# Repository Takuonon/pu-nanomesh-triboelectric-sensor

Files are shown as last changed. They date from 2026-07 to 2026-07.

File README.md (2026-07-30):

# All-PU Nanomesh Triboelectric Throat Sensor

This repository provides hardware, firmware, and software information for the
wireless acquisition system used with a triboelectric sensor. For the scientific
background, device concept, experimental results, and interpretation, please
refer to the associated paper.

If you use or refer to any part of this repository, please cite the paper listed
in the [Citation](#citation) section at the end of this README.

## Contents

```text
hardware/
  gerber/                       PCB fabrication outputs for the TENG module
firmware/
  xiao_nrf52840/
    xiao_nrf52840.ino           Arduino firmware for Seeed XIAO nRF52840
software/
  pyqt_gui/
    app.py                      PyQt GUI entry point
    data_source.py              Source interface used by the GUI
    data_source_ble.py          BLE acquisition backend
    ui_main.py                  GUI layout, plotting, filtering, CSV export
    requirements.txt            Python dependencies
docs/
  images/
    Analog_circuit.pdf          Analog front-end and MCU schematic
    FPCB.pdf                    Wireless module and FPCB design figure
    *.png                       README preview images generated from the PDFs
```

## Hardware

The hardware release provides the analog circuit figure, the wireless module
FPCB figure, and the PCB fabrication package for the TENG module. The Gerber job
file identifies the design as `TENG_module`, generated by KiCad 9.0.6.

### Circuit Configuration

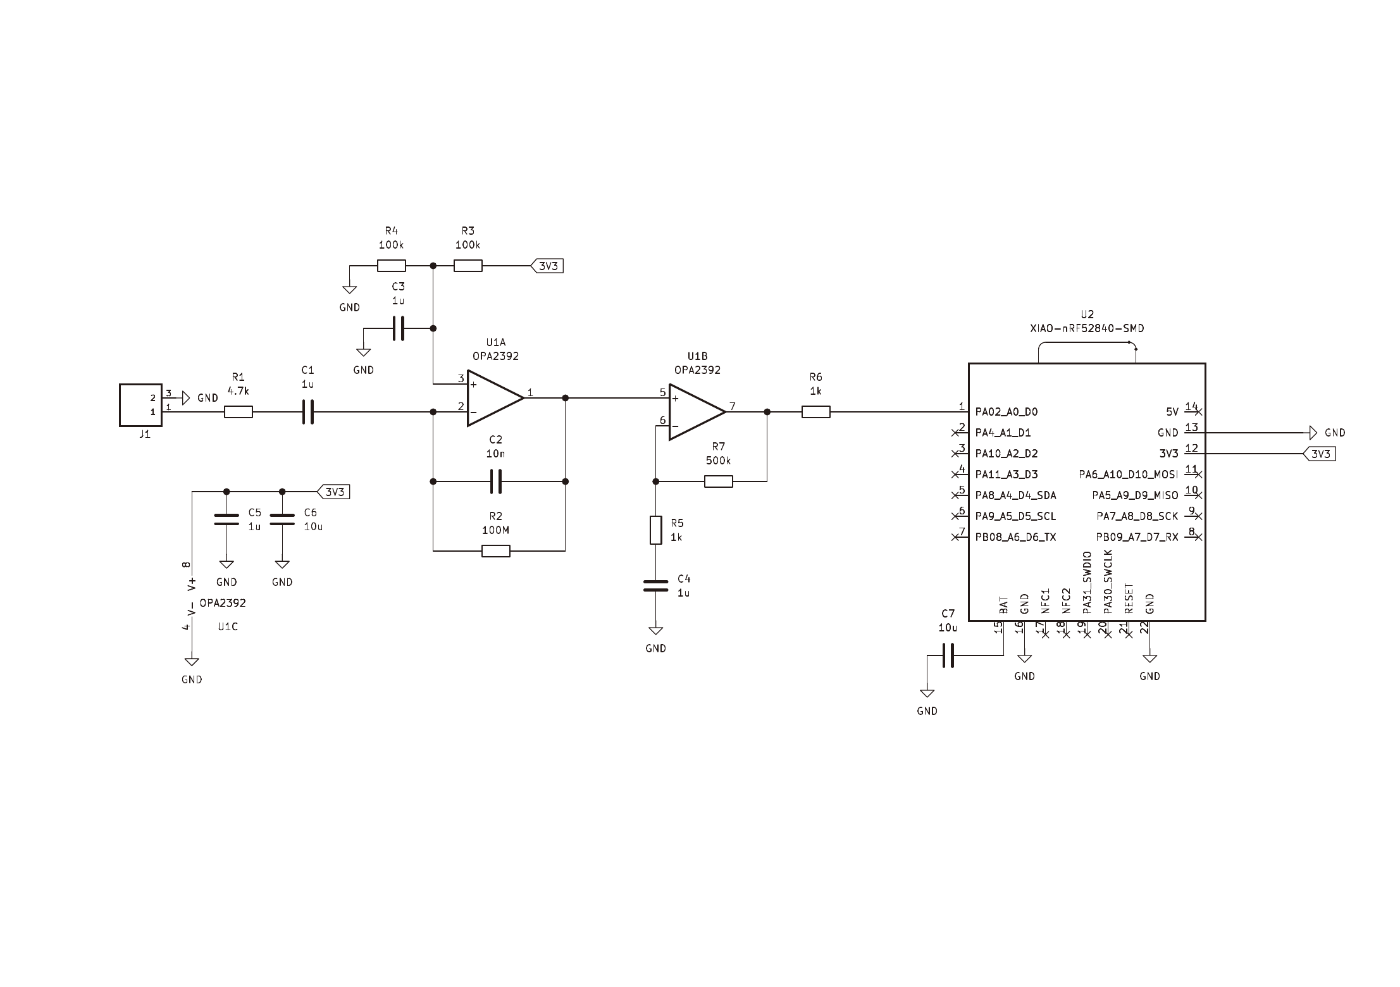
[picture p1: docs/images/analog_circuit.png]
Analog circuit


Source figure: [`Analog_circuit.pdf`](docs/images/Analog_circuit.pdf)

The acquisition circuit receives the triboelectric sensor output through the
input connector and routes it to an OPA2392-based two-stage analog front end.
The first stage is configured as a charge-amplifier stage for the high-impedance
triboelectric signal. The second stage provides voltage amplification and
conditioning before the signal is connected to the `A0` analog input of the
Seeed Studio XIAO nRF52840.

The XIAO nRF52840 performs ADC sampling for the conditioned triboelectric sensor
signal and sends the acquired data to the PC over BLE. The XIAO on-board PDM
microphone is used as the second acquisition channel in the firmware and GUI.

### Bill of Materials

| No. | Qty. | Description | Designator | Footprint | Value | Manufacturer Part | Manufacturer | Supplier Part | Supplier |
| --- | --- | --- | --- | --- | --- | --- | --- | --- | --- |
| 1 | 2 | SMD thin-film resistor | R5, R6 | R_0603 | 1 kOhm | ERA3AEB102V | Panasonic | C190613 | LCSC |
| 2 | 1 | SMD thin-film resistor | R1 | R_0603 | 4.7 kOhm | ERA3AEB472V | Panasonic | C473239 | LCSC |
| 3 | 2 | SMD thin-film resistor | R3, R4 | R_0603 | 100 kOhm | ERA3AEB104V | Panasonic | C190609 | LCSC |
| 4 | 1 | SMD thick-film resistor | R7 | R_0603 | 499 kOhm | ERJ3EKF4993V | Panasonic | C278628 | LCSC |
| 5 | 1 | SMD thick-film resistor | R2 | R_0805 | 100 MOhm | 0805W8F1006T5E | UNI-ROYAL | C169373 | LCSC |
| 6 | 1 | SMD capacitor | C2 | C_0603 | 10 nF | GRM1885C1H103JA01D | Murata | C85973 | LCSC |
| 7 | 4 | SMD capacitor | C1, C3, C4, C5 | C_0603 | 1 uF | GCM188R71E105KA64D | Murata | C85862 | LCSC |
| 8 | 2 | SMD capacitor | C6, C7 | C_0603 | 10 uF | GRM188Z71A106KA73D | Murata | C2959727 | LCSC |
| 9 | 1 | Operational amplifier | U1 |  | OPA2392DR | OPA2392DR | Texas Instruments | C22428420 | LCSC |
| 10 | 1 | BLE microcontroller module | U2 |  | Seeed Studio XIAO nRF52840 Sense |  | Seeed Studio |  | JD.com |
| 11 | 1 | Spring terminal block | J1 |  |  | 2059-302/998-403 | WAGO | C2765060 | LCSC |
| 12 | 1 | Lithium polymer battery |  |  | 3.7 V, 100 mAh | 302020-100mah | Taisko | C19632322 | LCSC |

### FPCB Design

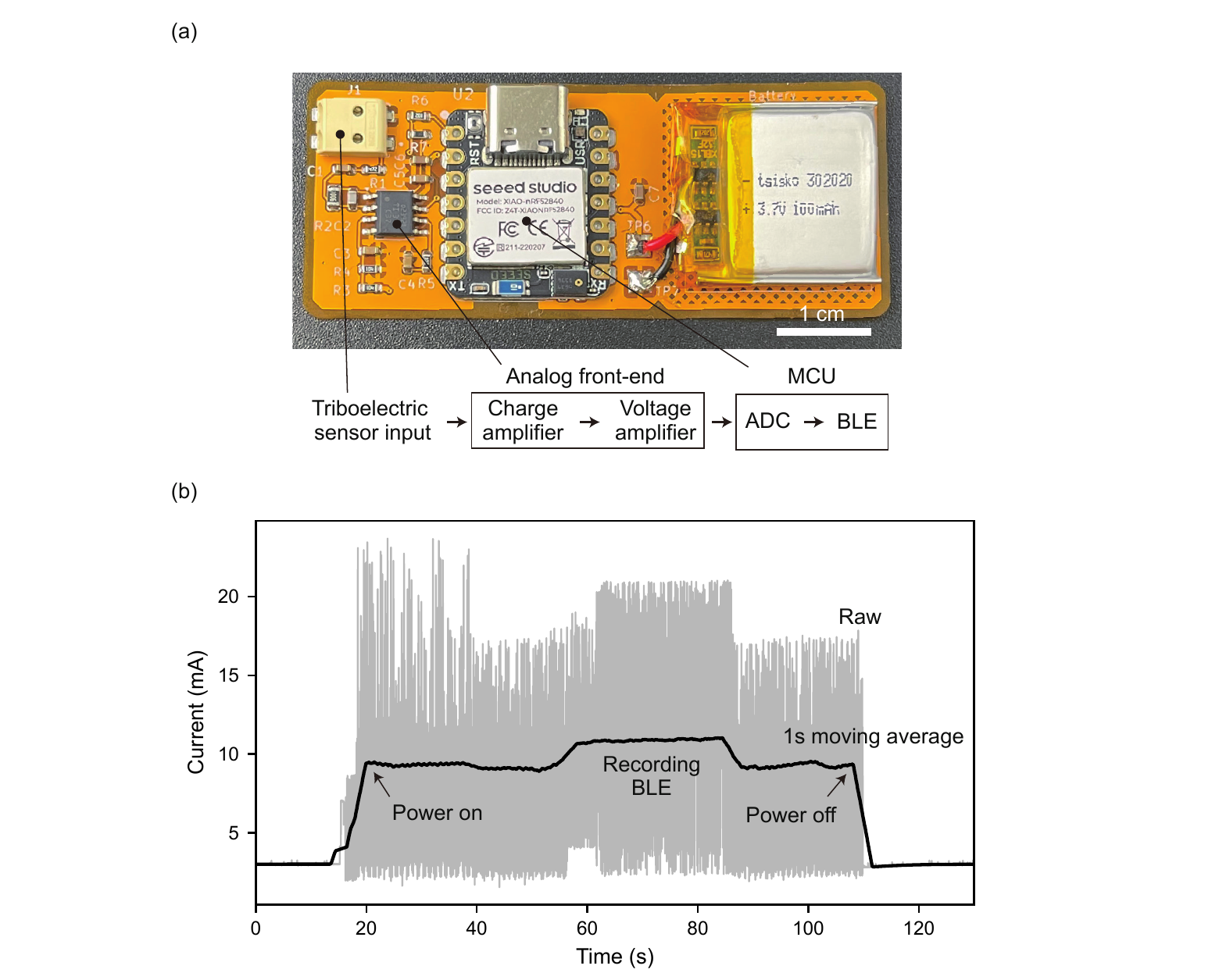
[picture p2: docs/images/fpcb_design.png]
FPCB design


Source figure: [`FPCB.pdf`](docs/images/FPCB.pdf)

Figure (a) shows the wireless module implemented on the FPCB. The board
integrates the triboelectric sensor input connector, the analog front-end
components, the XIAO nRF52840 module, and a small battery connection. The signal
flow is:

```text
Triboelectric sensor input -> charge amplifier -> voltage amplifier -> ADC -> BLE
```

Figure (b) shows the current consumption during module operation. The operating
current was approximately 10 mA; with a 100 mAh battery, the expected operating
time was approximately 10 h per charge.

Board metadata from `hardware/gerber/TENG_module-job.gbrjob`:

- Board size: 63.05 mm x 26.05 mm
- Layer count: 2 copper layers
- Board thickness: 1.6 mm
- Fabrication files: top/bottom copper, solder mask, solder paste, silkscreen,
  edge cuts, plated drill, non-plated drill, and Gerber job metadata

### Circuit Role

The hardware files describe the sensor-module PCB used with the all-PU
nanomesh triboelectric throat sensor. In the acquisition workflow, the sensor
signal is conditioned by the analog front end and connected to the XIAO
nRF52840 analog input (`A0`) as channel 1. The XIAO on-board PDM microphone is
used as channel 2 for simultaneous reference audio acquisition.

For analog acquisition, the firmware expects the channel-1 signal to stay
within the XIAO nRF52840 ADC input range. If a mid-supply bias is used by the
analog front end, the GUI subtracts the mean of channel 1 after capture for
visualization.

## Firmware

Firmware path: `firmware/xiao_nrf52840/xiao_nrf52840.ino`

The firmware turns a Seeed Studio XIAO nRF52840 into a BLE peripheral named
`XIAO-AUDIO`. It records two channels and transfers the captured block to the PC
after recording.

### Firmware Design Policy

- Keep the microcontroller workflow deterministic: record first, then transfer.
- Use fixed-size buffers to avoid dynamic allocation during acquisition.
- Store both channels against a shared 8 kHz sample index.
- Discard the first 1 s of samples as warm-up to reduce startup transients.
- Use BLE indications for acknowledged transfer rather than unacknowledged
  notifications.
- Keep the BLE protocol small: one control byte starts capture or shutdown.

### Sampling

- Channel 1: SAADC on `A0`, sampled at 8 kHz
- Channel 2: on-board PDM microphone, captured at 16 kHz and decimated by 2
- Storage and transfer rate: 8 kHz per channel
- Maximum stored samples: 32,000 samples per channel
- Maximum capture duration: 4 s
- Warm-up discard: 1 s before storing the requested capture window

### BLE Protocol

Service UUID:

```text
19B20000-E8F2-537E-4F6C-D104768A1214
```

CTRL characteristic, PC to XIAO:

```text
19B20001-E8F2-537E-4F6C-D104768A1214
```

Payload:

- `0x01` to `0x04`: capture duration in seconds
- `0xFF`: enter low-power System OFF

AUDIO characteristic, XIAO to PC:

```text
19B20002-E8F2-537E-4F6C-D104768A1214
```

Each AUDIO packet contains:

1. `seq`: 2-byte little-endian sequence number
2. `payload`: stereo interleaved little-endian `int16` samples

The payload format is:

```text
[ch1_0, ch2_0, ch1_1, ch2_1, ...]
```

The current firmware sends 50 stereo frames per packet, corresponding to 200
payload bytes plus the 2-byte sequence number.

### LED States

- Disconnected idle: red blink
- Connected idle: blue blink
- Recording: solid blue
- Transferring: solid green
- Shutdown acknowledgement: brief purple indication

## Software

Software path: `software/pyqt_gui/`

The PC software is a PyQt6 GUI that connects to the XIAO nRF52840 over BLE,
requests a capture, receives the interleaved two-channel data, and displays the
waveforms.

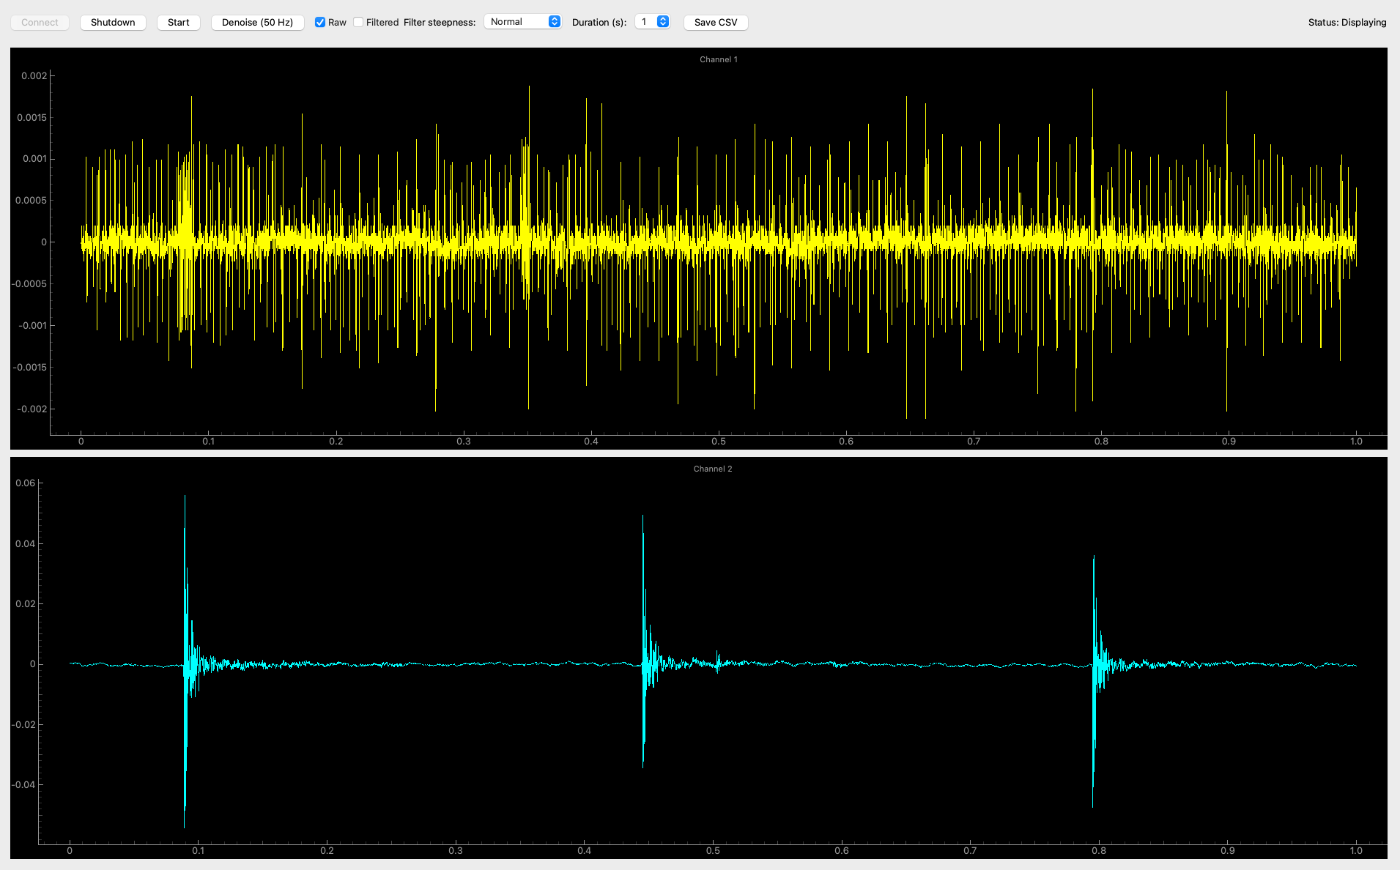
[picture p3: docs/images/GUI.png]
PyQt GUI


The GUI displays simultaneous two-channel recordings: the triboelectric sensor
signal in the upper yellow trace and the PDM microphone signal in the lower blue
trace.

### Software Design Policy

- Keep the UI independent from the acquisition backend through `BaseSource`.
- Use Bleak for BLE central-mode scanning, connection, control writes, and
  indication subscription.
- Convert received little-endian `int16` PCM data to normalized `float32` data
  for plotting.
- Display captured data only after the firmware completes record-then-transfer.
- Provide optional 50 Hz bandstop filtering for visual inspection.
- Preserve raw data and allow CSV export of the displayed two-channel buffer.

### Python Setup

The pinned requirements are macOS-oriented because BLE access through Bleak on
CoreBluetooth uses the `pyobjc` packages.

From the repository root:

```bash
python -m venv .venv
source .venv/bin/activate
python -m pip install -r software/pyqt_gui/requirements.txt
```

### Run

From the repository root:

```bash
python -m software.pyqt_gui.app
```

The GUI starts in BLE mode, attempts to connect to `XIAO-AUDIO`, and enables
capture controls after the BLE connection is ready. Select a duration from 1 to
4 s and press `Start`.

## Data Format

The received waveform data are two-channel, interleaved `int16` samples:

```text
seq_lsb seq_msb ch1_lsb ch1_msb ch2_lsb ch2_msb ...
```

The GUI converts this byte stream into a NumPy array with shape `(N, 2)`.
Channel 1 is the ADC input; channel 2 is the PDM microphone input.

## Notes

- The firmware uses a record-then-transfer workflow, so transfer begins only
  after acquisition is complete.
- A requested 4 s capture includes an additional 1 s warm-up discard before the
  stored samples are collected.
- BLE indications improve transfer reliability but may be slower than
  notifications.
- The current release contains fabrication outputs for the PCB. If editable CAD
  source files are needed, add them separately from the Gerber package.

## Citation

If you use or refer to any part of this repository in a publication,
presentation, thesis, dataset, or derived research project, please cite the
following paper, which describes the sensor system associated with these files:

```text
Takuo Tachibana, Yusuke Ebihara, Yi Kao, Manabu Ezumi, Yan Li,
Kento Yamagishi, Tomoyuki Yokota, Tian-Ling Ren, and Takao Someya,
"An All-Polyurethane Nanomesh Triboelectric Sensor for Swallowing and Voice Detection."
```

The citation information will be updated with journal, year, volume, pages, and
DOI after publication.

## License

The software, firmware, and circuit design files in this repository may be used
for research purposes.

See `LICENSE` for the full license text.

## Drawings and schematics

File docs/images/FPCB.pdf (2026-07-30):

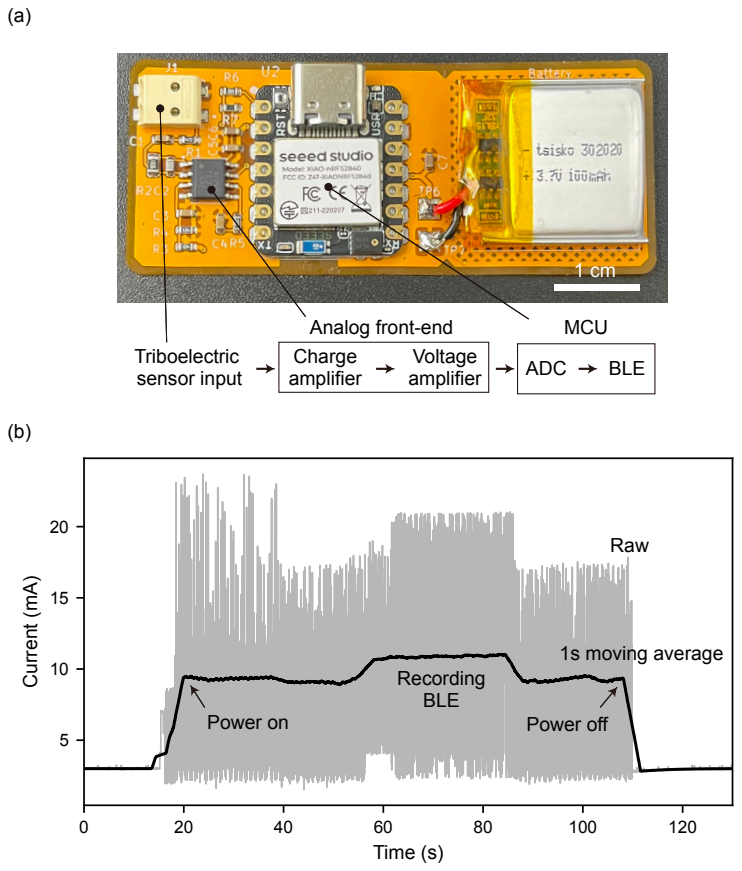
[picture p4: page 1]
Time (s); Current (mA); Raw; 1s moving average; Power on; Power off; Recording BLE; Triboelectric sensor input; Charge amplifier; Voltage; amplifier; ADC; BLE; Analog front-end; MCU

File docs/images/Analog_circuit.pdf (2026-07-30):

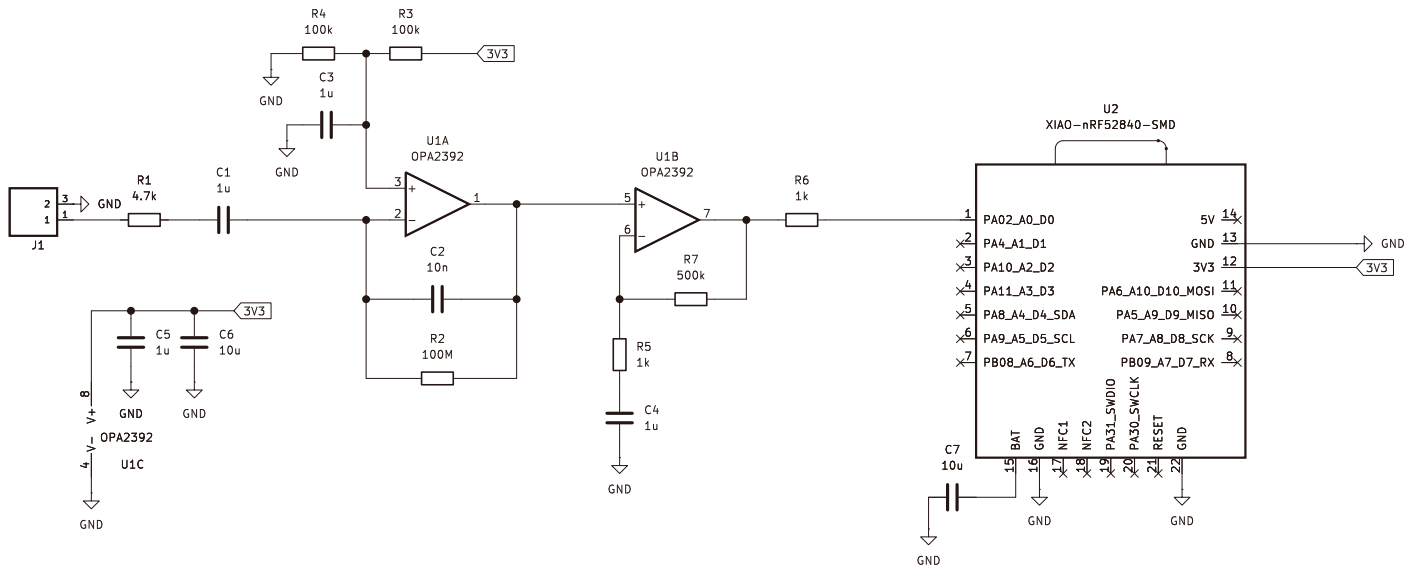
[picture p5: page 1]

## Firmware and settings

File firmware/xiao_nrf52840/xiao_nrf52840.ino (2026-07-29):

#include <Arduino.h>
#include <ArduinoBLE.h>
#include <PDM.h>

extern "C" {
  #include "nrfx_ppi.h"
  #include "nrf_saadc.h"
  #include "nrf_timer.h"
}

// ===================== BLE UUID =====================
BLEService audioService("19B20000-E8F2-537E-4F6C-D104768A1214");

BLEByteCharacteristic ctrlChar(
  "19B20001-E8F2-537E-4F6C-D104768A1214",
  BLERead | BLEWrite
);

BLECharacteristic audioChar(
  "19B20002-E8F2-537E-4F6C-D104768A1214",
  BLEIndicate,
  244
);

// ===================== Settings =====================
static const int PDM_CAPTURE_RATE = 16000;
static const int ADC_CAPTURE_RATE = 8000;
static const int STORE_RATE = 8000;

static const int MAX_NUM_SAMPLES = 32000;
static const int MAX_REC_SECONDS = MAX_NUM_SAMPLES / STORE_RATE; // 4

static constexpr uint32_t CHUNK_SAMPLES = 1024;
static const float WARMUP_DROP_SECONDS = 1.0f;

static const int PAYLOAD_BYTES = 200;
static const int FRAMES_PER_PKT = PAYLOAD_BYTES / 4;

// Shutdown command uses a value outside the normal capture-duration range.
static const byte CMD_SHUTDOWN = 0xFF; // 255

// ===================== Buffers =====================
static int16_t ch1_adc[MAX_NUM_SAMPLES];
static int16_t ch2_pdm[MAX_NUM_SAMPLES];

static volatile int adcWritten = 0;
static volatile int pdmWritten = 0;

static int16_t pdmBuf[256];

static int16_t saadcBuf0[CHUNK_SAMPLES];
static int16_t saadcBuf1[CHUNK_SAMPLES];
static int16_t* activeBuf = saadcBuf0;
static int16_t* nextBuf   = saadcBuf1;

// ===================== Recording control =====================
static volatile bool recording = false;
static volatile int targetSamples = STORE_RATE;
static volatile int warmupDropPDM = 0;
static volatile int warmupDropADC = 0;

static volatile uint8_t pdmDecimPhase = 0;

// ===================== TIMER4 + PPI =====================
static NRF_TIMER_Type* const TMR = NRF_TIMER4;
static nrf_ppi_channel_t ppiCh;

// ===================== LED =====================
static const bool LED_ACTIVE_LOW = true;

enum DeviceState {
  STATE_IDLE_DISCONNECTED = 0,
  STATE_IDLE_CONNECTED = 1,
  STATE_RECORDING = 2,
  STATE_COMMUNICATING = 3,
};

static DeviceState gState = STATE_IDLE_DISCONNECTED;
static unsigned long gBlinkLastMs = 0;
static bool gBlinkOn = false;

static inline void ledWrite(uint8_t pin, bool on) {
  if (LED_ACTIVE_LOW) digitalWrite(pin, on ? LOW : HIGH);
  else digitalWrite(pin, on ? HIGH : LOW);
}
static inline void ledsAllOff() {
  ledWrite(LEDR, false);
  ledWrite(LEDG, false);
  ledWrite(LEDB, false);
}
static void setState(DeviceState st) {
  gState = st;
  if (gState == STATE_RECORDING) {
    ledWrite(LEDR, false); ledWrite(LEDG, false); ledWrite(LEDB, true);   // blue
  } else if (gState == STATE_COMMUNICATING) {
    ledWrite(LEDR, false); ledWrite(LEDG, true);  ledWrite(LEDB, false);  // green
  } else {
    ledsAllOff();
    gBlinkLastMs = millis();
    gBlinkOn = false;
  }
}
static void updateIdleBlink() {
  if (gState != STATE_IDLE_DISCONNECTED && gState != STATE_IDLE_CONNECTED) return;
  const unsigned long now = millis();
  if (now - gBlinkLastMs >= 500) {
    gBlinkLastMs = now;
    gBlinkOn = !gBlinkOn;
    if (gState == STATE_IDLE_DISCONNECTED) {
      ledWrite(LEDR, gBlinkOn); ledWrite(LEDG, false); ledWrite(LEDB, false);
    } else {
      ledWrite(LEDR, false); ledWrite(LEDG, false); ledWrite(LEDB, gBlinkOn);
    }
  }
}

// ===================== PDM callback =====================
void onPDMdata() {
  int bytesAvailable = PDM.available();
  if (bytesAvailable <= 0) return;

  int samples = bytesAvailable / 2;
  if (samples > (int)(sizeof(pdmBuf) / sizeof(pdmBuf[0]))) {
    samples = sizeof(pdmBuf) / sizeof(pdmBuf[0]);
  }
  PDM.read(pdmBuf, samples * 2);

  if (!recording) return;

  for (int i = 0; i < samples; i++) {
    if (warmupDropPDM > 0) {
      warmupDropPDM--;
      if (warmupDropPDM == 0) {
        pdmDecimPhase = 0;
      }
      continue;
    }

    if (pdmDecimPhase) {
      pdmDecimPhase = 0;
      continue;
    }
    pdmDecimPhase = 1;

    int idx = pdmWritten;
    if (idx >= targetSamples) {
      return;
    }
    ch2_pdm[idx] = pdmBuf[i];
    pdmWritten++;
  }
}

// ===================== SAADC init (register) =====================
static void timer4_init_16khz() {
  TMR->TASKS_STOP  = 1;
  TMR->TASKS_CLEAR = 1;
  TMR->MODE      = TIMER_MODE_MODE_Timer;
  TMR->BITMODE   = TIMER_BITMODE_BITMODE_32Bit;
  TMR->PRESCALER = 0;
  TMR->CC[0]     = 16000000UL / ADC_CAPTURE_RATE;
  TMR->SHORTS    = TIMER_SHORTS_COMPARE0_CLEAR_Msk;
  TMR->EVENTS_COMPARE[0] = 0;
}

static void saadc_init_ain0_reg() {
  NRF_SAADC->ENABLE = (SAADC_ENABLE_ENABLE_Enabled << SAADC_ENABLE_ENABLE_Pos);
  NRF_SAADC->RESOLUTION = SAADC_RESOLUTION_VAL_12bit;

  NRF_SAADC->CH[0].PSELP = SAADC_CH_PSELP_PSELP_AnalogInput0;
  NRF_SAADC->CH[0].PSELN = SAADC_CH_PSELN_PSELN_NC;

  NRF_SAADC->CH[0].CONFIG =
      (SAADC_CH_CONFIG_REFSEL_Internal << SAADC_CH_CONFIG_REFSEL_Pos) |
      (SAADC_CH_CONFIG_GAIN_Gain1_6     << SAADC_CH_CONFIG_GAIN_Pos)   |
      (SAADC_CH_CONFIG_TACQ_10us        << SAADC_CH_CONFIG_TACQ_Pos)   |
      (SAADC_CH_CONFIG_MODE_SE          << SAADC_CH_CONFIG_MODE_Pos)   |
      (SAADC_CH_CONFIG_RESP_Bypass      << SAADC_CH_CONFIG_RESP_Pos)   |
      (SAADC_CH_CONFIG_RESN_Bypass      << SAADC_CH_CONFIG_RESN_Pos);

  activeBuf = saadcBuf0;
  nextBuf   = saadcBuf1;

  NRF_SAADC->RESULT.PTR    = (uint32_t)activeBuf;
  NRF_SAADC->RESULT.MAXCNT = CHUNK_SAMPLES;

  NRF_SAADC->EVENTS_END = 0;
  NRF_SAADC->EVENTS_STARTED = 0;
}

static void ppi_connect_timer_to_saadc_sample() {
  nrfx_ppi_channel_alloc(&ppiCh);
  const uint32_t evt_addr  = (uint32_t)&TMR->EVENTS_COMPARE[0];
  const uint32_t task_addr = (uint32_t)&NRF_SAADC->TASKS_SAMPLE;
  nrfx_ppi_channel_assign(ppiCh, evt_addr, task_addr);
  nrfx_ppi_channel_enable(ppiCh);
}

static inline void consume_saadc_samples(const int16_t* buf, int n) {
  for (int i = 0; i < n; i++) {
    if (warmupDropADC > 0) {
      warmupDropADC--;
      continue;
    }
    int idx = adcWritten;
    if (idx >= targetSamples) return;
    ch1_adc[idx] = buf[i];
    adcWritten++;
  }
}

// ===================== Record control =====================
static bool startRecordingBoth(int seconds) {
  if (seconds < 1) seconds = 1;
  if (seconds > MAX_REC_SECONDS) seconds = MAX_REC_SECONDS;

  targetSamples = STORE_RATE * seconds;

  adcWritten = 0;
  pdmWritten = 0;

  warmupDropPDM = (int)(PDM_CAPTURE_RATE * WARMUP_DROP_SECONDS);
  warmupDropADC = (int)(ADC_CAPTURE_RATE * WARMUP_DROP_SECONDS);
  pdmDecimPhase = 0;

  recording = true;

  PDM.onReceive(onPDMdata);
  if (!PDM.begin(1, PDM_CAPTURE_RATE)) {
    recording = false;
    return false;
  }

  NRF_SAADC->EVENTS_CALIBRATEDONE = 0;
  NRF_SAADC->TASKS_CALIBRATEOFFSET = 1;
  delay(10);

  NRF_SAADC->EVENTS_STARTED = 0;
  NRF_SAADC->TASKS_START = 1;
  for (volatile int i = 0; i < 20000 && NRF_SAADC->EVENTS_STARTED == 0; i++) {}

  NRF_SAADC->TASKS_SAMPLE = 1;

  TMR->TASKS_CLEAR = 1;
  TMR->TASKS_START = 1;

  return true;
}

static void stopRecordingBoth() {
  recording = false;

  TMR->TASKS_STOP = 1;
  NRF_SAADC->TASKS_STOP = 1;
  PDM.end();
}

// ===================== Low-power shutdown =====================
// Enter this path when CMD_SHUTDOWN (255) is received over BLE.
// Wake-up from System OFF requires pressing RESET or power-cycling the board.
static void enterSystemOffNow() {
  // Show shutdown acknowledgement in purple (red + blue).
  ledWrite(LEDR, true);
  ledWrite(LEDG, false);
  ledWrite(LEDB, true);
  delay(150);  // Briefly visible to the user.

  // Turn LEDs off just before shutdown.
  ledsAllOff();
  delay(50);

  // Stop peripherals defensively.
  stopRecordingBoth();
  nrfx_ppi_channel_disable(ppiCh);
  NRF_SAADC->ENABLE = (SAADC_ENABLE_ENABLE_Disabled << SAADC_ENABLE_ENABLE_Pos);

  // Give BLE a short grace period to stop cleanly.
  BLE.stopAdvertise();
  BLE.disconnect();
  delay(100);

  // Enter System OFF.
  NRF_POWER->SYSTEMOFF = 1;

  // Execution should not return here.
  while (1) {}
}

// ===================== Send: stereo interleave =====================
static void sendRecordedStereoInterleaved(int nSamples) {
  uint16_t seq = 0;
  uint8_t packet[2 + FRAMES_PER_PKT * 4];

  int idx = 0;
  while (idx < nSamples) {
    int frames = nSamples - idx;
    if (frames > FRAMES_PER_PKT) frames = FRAMES_PER_PKT;

    packet[0] = (uint8_t)(seq & 0xFF);
    packet[1] = (uint8_t)((seq >> 8) & 0xFF);

    uint8_t* p = packet + 2;
    for (int i = 0; i < frames; i++) {
      int16_t a = ch1_adc[idx + i];
      int16_t b = ch2_pdm[idx + i];

      *p++ = (uint8_t)(a & 0xFF);
      *p++ = (uint8_t)((a >> 8) & 0xFF);
      *p++ = (uint8_t)(b & 0xFF);
      *p++ = (uint8_t)((b >> 8) & 0xFF);
    }

    audioChar.writeValue(packet, 2 + frames * 4);
    idx += frames;
    seq++;
    delay(5);
  }
}

// ===================== BLE main =====================
void setup() {
  Serial.begin(115200);
  unsigned long t0 = millis();
  while (!Serial && (millis() - t0) < 2000) delay(10);

  pinMode(LEDR, OUTPUT);
  pinMode(LEDG, OUTPUT);
  pinMode(LEDB, OUTPUT);
  ledsAllOff();
  setState(STATE_IDLE_DISCONNECTED);

  timer4_init_16khz();
  saadc_init_ain0_reg();
  ppi_connect_timer_to_saadc_sample();

  if (!BLE.begin()) {
    Serial.println("BLE.begin failed");
    while (1) {}
  }

  BLE.setLocalName("XIAO-AUDIO");
  BLE.setDeviceName("XIAO-AUDIO");
  BLE.setAdvertisedService(audioService);

  audioService.addCharacteristic(ctrlChar);
  audioService.addCharacteristic(audioChar);
  BLE.addService(audioService);

  ctrlChar.writeValue((byte)0);

  BLE.advertise();
  Serial.println("BLE Audio Peripheral Ready (ADC ch1 + PDM ch2, interleaved)");
}

void loop() {
  BLEDevice central = BLE.central();
  if (!central) {
    if (gState != STATE_IDLE_DISCONNECTED) setState(STATE_IDLE_DISCONNECTED);
    updateIdleBlink();
    delay(10);
    return;
  }

  Serial.print("Connected: ");
  Serial.println(central.address());
  setState(STATE_IDLE_CONNECTED);

  while (central.connected()) {
    updateIdleBlink();

    if (ctrlChar.written()) {
      byte cmd = ctrlChar.value();

      // Shutdown command (255).
      if (cmd == CMD_SHUTDOWN) {
        Serial.println("CMD_SHUTDOWN received. Going SYSTEM OFF...");
        // Optionally write an acknowledgement to CTRL here if needed.
        // ctrlChar.writeValue((byte)0);
        delay(50);
        enterSystemOffNow();
      }

      // Normal commands: 1..MAX_REC_SECONDS represent capture duration in seconds.
      if (cmd >= 1 && cmd <= (byte)MAX_REC_SECONDS) {
        byte secs = cmd;

        setState(STATE_RECORDING);

        bool ok = startRecordingBoth((int)secs);
        if (!ok) {
          setState(STATE_IDLE_CONNECTED);
          ctrlChar.writeValue((byte)0);
          continue;
        }

        while (central.connected()) {
          if (NRF_SAADC->EVENTS_END) {
            NRF_SAADC->EVENTS_END = 0;

            TMR->TASKS_STOP = 1;

            consume_saadc_samples(activeBuf, (int)CHUNK_SAMPLES);

            if (adcWritten >= targetSamples && pdmWritten >= targetSamples) {
              break;
            }

            int16_t* tmp = activeBuf;
            activeBuf = nextBuf;
            nextBuf = tmp;

            NRF_SAADC->RESULT.PTR    = (uint32_t)activeBuf;
            NRF_SAADC->RESULT.MAXCNT = CHUNK_SAMPLES;

            NRF_SAADC->TASKS_STOP = 1;
            NRF_SAADC->TASKS_START = 1;
            NRF_SAADC->TASKS_SAMPLE = 1;

            TMR->TASKS_CLEAR = 1;
            TMR->TASKS_START = 1;
          }

          delay(1);
        }

        stopRecordingBoth();

        int nSend = adcWritten;
        if (pdmWritten < nSend) nSend = pdmWritten;
        if (nSend > targetSamples) nSend = targetSamples;

        Serial.print("Recorded adc=");
        Serial.print(adcWritten);
        Serial.print(" pdm=");
        Serial.print(pdmWritten);
        Serial.print(" -> send=");
        Serial.println(nSend);

        setState(STATE_COMMUNICATING);
        sendRecordedStereoInterleaved(nSend);
        setState(STATE_IDLE_CONNECTED);

        ctrlChar.writeValue((byte)0);
        Serial.println("Send done.");
      }
    }

    delay(5);
  }

  Serial.print("Disconnected: ");
  Serial.println(central.address());
  setState(STATE_IDLE_DISCONNECTED);
}
